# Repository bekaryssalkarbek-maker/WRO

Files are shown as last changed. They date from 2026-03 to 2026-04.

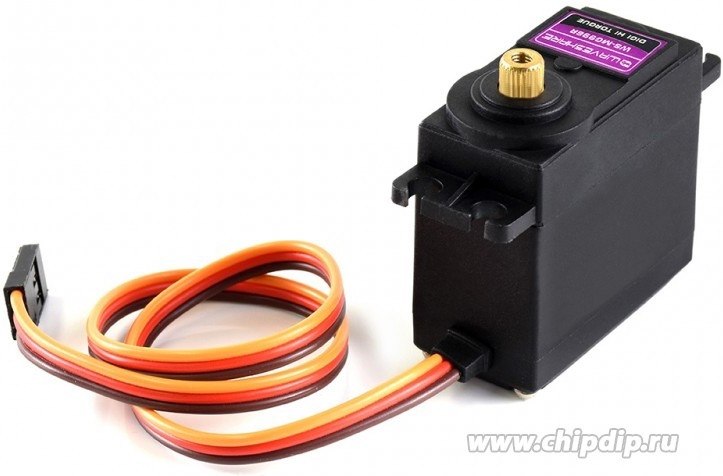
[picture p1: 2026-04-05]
Electronical components(photos)/mg996r v17.jpg

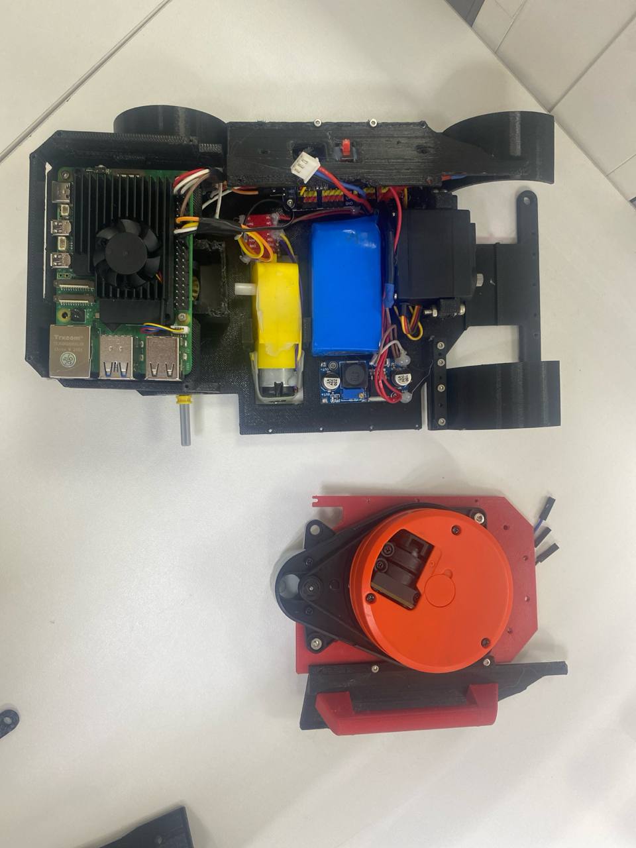
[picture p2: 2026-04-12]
Non-elecrtonical components(models)/building steps.jpg

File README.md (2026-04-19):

# 🚀 WRO 2025 Future Engineers – CyberBots
Welcome to the GitHub repository of Team CyberBots, participating in the World Robot Olympiad™ (WRO®) Future Engineers 2026 category. Our team designed and developed a compact autonomous vehicle inspired by real-world automotive engineering principles, with a design approach that visually reflects concepts similar to real vehicles and Mars rover-style exploration systems.

Our main objective was to build a robot that not only successfully completes the WRO challenge but also incorporates a realistic automotive-inspired design language. The external structure was intentionally designed to resemble a real vehicle in terms of proportions and layout, while maintaining full compliance with WRO constraints. Special attention was given to mechanical reliability, precise steering geometry, stable power architecture, sensor-based navigation, and modular electronic integration.

During development, each subsystem — including drivetrain, steering mechanism, perception system, onboard computing, and power distribution — was iteratively tested and optimized to achieve stable performance on the official 3 × 3 meter WRO competition field.

This repository documents our full engineering workflow, including system architecture, electrical schematics, component selection rationale, software logic structure, testing procedures, and validation results prepared for the WRO 2026 Future Engineers competition.

## 📚Table of Contents
## 📁 Project Structure

- 💾 Code
- 🔌 Electronical Components (CAD)
- 🔌 Electronical Components(photos)
- 📚 Engineer Journal
- ⚙  Non-Electronical Components
- 🔌 Schemes
- 👥 Team
- 🚗 Vehicle Photos
- 📁 SRC

## 📂Complete Documentation Structure
### Each folder contains comprehensive README documentation with specialized technical content
| 📁 Folder | 🎯 Technical Content | 
|---|---|
|  💾 Code | Software System |
|  | • Autonomous navigation algorithms |
| | • Camera color detection logic |
| | • LiDAR-based distance processing |
| | • Motor and steering control systems |
|  |
| 🔌 Electronical Components (CAD) | Electrical Design Models |
| | • CAD models of electronic layout |
| | • Component placement and integration |
| |  |
| 🔌 Electronical Components (Photos) | Electronics Implementation |
| | • Real photos of all electronic components |
| | • Individual component descriptions |
| | • Engineering problems and solutions |
| |  |
| 📚 Engineer Journal | Engineering Development Process |
| | • Design iterations and improvements |
| | • Problem solving and optimization |
| | • System-level engineering decisions |
| |  |
| ⚙ Non-Electronical Components | Mechanical Design |
| | • Full robot CAD model |
| | • Differential system design |
| | • Steering mechanism design |
| | • Chassis and structural architecture |
| | • 3D printing process and assembly stages |
| | • Design challenges and solutions |
| | • Individual CAD explanations for parts |
| |  |
| 🔌 Schemes | Electrical System Documentation |
| | • Electronics overview (photos + specs + quantity) |
| | • Full wiring schematic and system logic |
| | • Power distribution and current flow strategy |
| | • Assembly process of electrical system |
| | • Engineering problems and solutions |
| |  |
| 👥 Team | Team Information |
| | • Team members and roles |
| | • Coach/mentor information |
| | • Task distribution (mechanical, electronics, software, testing) |
| |  |
| 🚗 Vehicle Photos | Robot Documentation |
| | • CAD renders of robot |
| | • Real robot photos |
| | • Multi-angle system overview |
| |  |
| 📁 SRC | Testing & Resources |
| | • Autonomous navigation tests |
| | • Steering and drivetrain performance tests |
| | • Sensor calibration and validation |
| | • Competition condition testing |
| | • Debugging and additional resources |
| |  |

## 👥The Team
Team CyberBots includes passionate students working under the guidance of a coach. This is our first time competing in the WRO Future Engineers category (2026), where each member contributes unique skills to the project, including mechanical design, electronics, programming, and computer vision development.

Bekarys Shalkarbek
- Role: CAD modeling, electronics support, robot training and software development under coach supervision
- Background: 10th grade student, NIS FMN Astana
- Born: 2008, Kazakhstan
- Contact: bekaryssalkarbek@gmail.com

Anas Rustam
- Role: Engineering support, electronics integration, hardware development
- Background: School student
- Born: Kazakhstan

Coach:
Nursultan Bahit
- Role: Embedded Systems Engineer, CAD Designer, Robotics Engineer, Software & Backend Developer
- Background: Bachelor Degree, Cybersecurity, Astana IT University
- Born: 04.02.2007, Taraz, Kazakhstan
- Contact: nursultanbahit409@gmail.com

## 🎯Challenge Overview
### **Two distinct autonomous navigation challenges testing vehicle intelligence and precision**

</div>

### **🚀 Open Challenge**
<div align="center">

**Objective**: Complete three autonomous laps on dynamically configured tracks

| Aspect | Challenge | Our Solution |
|---|---|---|
| **Track Variability** | Random internal wall placements | Adaptive path planning algorithms |
| **Navigation** | Unknown track layouts each round | Robust wall-following with corner detection |
| **Performance** | Consistent lap times across variations | Optimized PID control and sensor fusion |
| **Precision** | Maintain course in narrow lanes | High-accuracy steering and speed control |

</div>

### **🚧 Obstacle Challenge**
<div align="center">

**Objective**: Navigate three laps with traffic sign compliance and precision parking

| Challenge Element | Requirement | Our Implementation |
|---|---|---|
| **Traffic Signs** | Red → Right bias<br>Green → Left bias | Real-time color detection with LAB colorspace |
| **Obstacle Avoidance** | Dynamic path adjustment | Smooth following at consistent distances |
| **Parking Maneuver** | Parallel parking after lap completion | Multi-stage parking with sensor validation |
| **Navigation** | Shortest path optimization | Efficient routing around obstacle combinations |
</div>

## 📊 **WRO 2025 Engineering Documentation Scoring (30 points total)**

| Scoring Area | Maximum Points | Our Documentation Coverage |
|---|---|---|
| **1. Mobility Management** | 4 points | Complete mechanical design, motor selection, steering system, assembly instructions |
| **2. Power & Sense Management** | 4 points | Power systems, sensor integration, wiring diagrams, component specifications |
| **3. Obstacle Management** | 4 points | Navigation algorithms, parking strategies, source code with detailed comments |
| **4. Pictures – Team and Vehicle** | 4 points | Multi-angle vehicle photos, team photos, component labeling |
| **5. Performance Videos** | 4 points | Complete challenge demonstrations with commentary and analysis |
| **6. GitHub Utilization** | 4 points | Version control, structured documentation, regular commits |
| **7. Engineering Factor** | 4 points | Custom design and manufacturing throughout the vehicle |
| **8. Overall Judge Impression** | 2 points | Clear communication enabling easy replication |
| **Total Documentation Score** | **30 points** | **(≈25% of total competition score)** |
</div>

## 🤖Our Robot
### **Vehicle Photos**
The following folder contain the final assembled robot from different perspectives. They demonstrate the chassis structure, steering mechanism, drivetrain layout, bumper design, LED headlights, and placement of key electronic components such as the Raspberry Pi and LiDAR sensor.

### **Photos**
#### **Front photo**
**Focus:** Lidar, Camera, Stearing system, LED headlights
- Lidar: Xiaomi Lidar Sensor (Used for distance measurement and obstacle detection to support accurate navigation and safe robot movement during competition runs.)
- Camera: USB 8MP 4K 60fps Camera(Used for color detection and environment recognition to support navigation decisions during robot movement, while distance measurement is handled by the LiDAR sensor.)
- Stearing system: Mechanism responsible for controlling the direction of the robot’s front wheels, enabling precise turning and stable navigation during movement.
- LED headlights: Used primarily for aesthetic purposes, improving the robot’s visual appearance without affecting its functional performance during operation

Front photo

#### Core Processing Architecture
- Primary Computing Unit:Raspberry Pi 5 (1GB) single-board computer with Quad-core 2.4 GHz Cortex-A76 CPU, VideoCore VII GPU, Wi-Fi 802.11ac, Bluetooth 5.0, and 40-pin GPIO interface. Responsible for vision processing, LiDAR data handling, navigation logic, and overall system coordination.
- PWM Control Expansion:PCA9685 16-Channel PWM Driver (I2C) with 12-bit resolution (4096 steps) and adjustable PWM frequency (24–1526 Hz), used for stable actuator signal generation and precise control of steering systems.
- Distributed Control Strategy:Separation between high-level navigation processing on Raspberry Pi 5 and low-level motor actuation through DRV8833 dual H-bridge motor driver ensures reliable real-time control performance.

#### Perception System
- Front Visual Navigation:USB 8MP Camera with IMX415 sensor supporting 4K resolution and wide-angle field of view, used for track detection, color recognition, and environmental interpretation.
- Environmental Mapping:RPLIDAR 360° laser scanner with approximately 10–12 meters measurement range, enabling obstacle detection and spatial awareness during autonomous navigation.
- Sensor Fusion Logic:Combined processing of camera-based visual perception and LiDAR distance measurements improves navigation reliability under varying competition conditions.

#### Propulsion and Control
- Drive System:TT DC Gear Motor (3–6 V, gear ratio 1:48) with 130–290 RPM no-load speed and 160–240 mA no-load current provides stable drivetrain motion.
- Steering Mechanism:MG996R V17 Digital Servo Motor with metal gears, operating voltage 4.8–7.2 V, speed 0.17 s/60°, and approximately 180° rotation range enables precise steering control.
- Motor Control Interface:DRV8833 Dual H-Bridge Motor Driver supporting 2.7–10.8 V operating voltage and up to 1.5 A per channel output current with PWM speed control capability.
- Power Management Architecture:Custom 2S LiPo Battery (7.4 V, 3000 mAh) combined with HW-411 LM2596 DC-DC Buck Converter (input 4–40 V, output 1.25–35 V adjustable, up to 3 A) ensures stable voltage regulation across all subsystems.
- Electrical Safety Control:SS12D10 SPDT Slide Switch (90°) used as the primary system power isolation switch for safe startup and shutdown operations.

### Potential Future Improvements (Overall Vehicle)

- Improve vehicle speed by integrating a more powerful drivetrain motor with higher torque and better acceleration characteristics while maintaining the current robot dimensions. This upgrade will increase responsiveness and allow faster navigation on the competition track.
- Enhance drivetrain efficiency by optimizing gear ratio selection and reducing mechanical friction within the transmission system. These improvements will support smoother motion and more stable high-speed performance.
- Further improve power distribution stability to support higher peak acceleration without voltage drops by refining voltage regulation stages and optimizing current flow between computing, sensing, and actuation subsystems.

## 🔧 Electronic Systems
| Components | Image  | Description | Quantity | 
|---|---|---|---|
| Battery 7.4V |  Battary 7 4 v | Lithium polymer battery pack / custom 2S LiPo battery – 7.4V, 3000mAh, Charge 0.5C, Discharge 1C, Size 13×42.5×98 mm, Weight ~108 g. | 1  | 
| yellow toymotor dims |  yellow_toymotor_dims |Yellow DC 3V–6V Gear Motor TT for Intelligent Car / Robot Wheels – Voltage 3–6V, No-load current 160–240 mA, No-load speed 130–290 rpm, Gear ratio 1:48, Single axis. |  1  | 
| mg996r v17 | mg996r v17 | MG996R V17 Servo Motor – High torque, Digital, Rotation ~180°, Operating voltage 4.8–7.2 V, Speed 0.17 s/60° (6 V), Metal gears, Standard size. | 1 | 
| HW-411 | HW-411 | HW‑411 DC‑DC Buck Converter Module – Adjustable step‑down voltage regulator (LM2596S), Input 4–40 V, Output 1.25–35 V (adjustable), Max current ≈3 A, High efficiency (~92%), Overheat and short‑circuit protectio | 2 | 
| USB 8MP 4K 60fps Camera | Cam V2 1 v1 | USB 8MP 4K 60fps Camera with IMX415 Sensor and Microphone, Day & Night Wide-Angle Surveillance HD CCTV System |  1  | 
| DRV8833 | DRV8833  | DRV8833 Dual DC Motor Driver Module – Dual H-bridge motor driver, operating voltage 2.7–10.8 V, controls 2 DC motors, output current 1.5 A per channel, supports PWM control, built-in protection circuits. |  1  | 
| PCA9685 v18 | PCA9685 v18  | PCA9685 16-Channel PWM Servo Driver Module (I2C) – Controls up to 16 servos, 12-bit PWM resolution (4096 steps), communication via I2C (SDA/SCL), logic voltage 3.3 V / 5 V compatible, adjustable PWM frequency ≈24–1526 Hz, supports chaining up to 62 modules. |  1 | 
| RASPBERRY_PI5_1 | RASPBERRY_PI5_1  | Raspberry Pi 5 (1GB) – Quad-core 2.4 GHz Cortex-A76 CPU, 1 GB LPDDR4X RAM, VideoCore VII GPU, Wi-Fi (802.11ac) + Bluetooth 5.0, Gigabit Ethernet, 2× USB 3.0 + 2× USB 2.0, dual 4K HDMI output, PCIe 2.0, 40-pin GPIO, power 5 V / 5 A via USB-C. |  1  |
| RPLIDAR | RPLIDAR  | Xiaomi LiDAR Sensor (e.g., TOF / 360°)* – Long‑range distance measurement up to ~10–12 m, 360° scanning, high‑precision time‑of‑flight (ToF) / laser ranging, fast sampling, low‑power, interface UART / I2C / SPI (зависит от модели), used for SLAM and robot navigation. |  1  | 
| SS12D10_90_Degree | SS12D10_90_Degree | SS12D10 90° Slide Switch (DIP) – SPDT slide switch, 90° actuation, DIP package, rated current ≈0.3–1 A, voltage ≈12–24 V DC, used for power/control switching in circuits. | 1  | 

**Component Sourcing Rules:** Direct product links and pricing information are intentionally not included to ensure long-term accessibility and avoid outdated references. All listed components can be easily found online using their names and images, while their authenticity can be confirmed through the datasheets provided in this repository.

### **⚡️Complete Wiring System**
#### **Wiring Schematic & Physical Implementation**
#### **1**
full scheme

#### **2**




1) Complete hand-drawn and digitally traced wiring schematic showing full electrical connections
2) Physical implementation demonstrating socket-based construction of the schematic

## Power Management Innovation

During system integration, we identified the necessity of implementing a stable and efficient power distribution architecture capable of supporting both high-current drivetrain components and sensitive computing modules operating simultaneously.

Our robot uses a 7.4V (2S) LiPo battery as the primary energy source. To ensure reliable voltage regulation for onboard electronics, we implemented a dedicated power management structure based on the HW-411 (LM2596) DC-DC buck converter module, providing stable regulated voltage for critical subsystems including the Raspberry Pi 5, sensors, and control electronics.

To improve operational safety and prevent unintended battery discharge during inactive states, an SS12D10 SPDT slide switch was integrated as the primary hardware-level power isolation mechanism controlling system startup and shutdown.

Additionally, we applied a separated power distribution strategy between computational modules and actuator subsystems. This approach reduces electrical noise from motors, prevents voltage drops during peak load conditions, and improves overall stability of perception and navigation performance during autonomous operation.

This structured power architecture significantly increases electrical reliability, protects sensitive components, and ensures consistent system behavior under dynamic competition conditions.

### Engineering Solution:

- **Structural Layout Optimization:** Internal components reorganized using electronics-first placement to avoid interference and improve weight distribution.

- **Mechanical Strength vs Weight Optimization:** Gyroid infill selected after testing multiple patterns to achieve best balance of strength and low weight.

- **Sensor Integration Stability:** Dedicated mounts and cable routing implemented for stable LiDAR and camera operation without mechanical interference.

### Modular Manufacturing Strategy Advantages
Our robot architecture was intentionally designed to support iterative development and serviceability during competition preparation:

- Rapid mechanical adjustments without external fabrication delays
- Independent subsystem upgrades without full system redesign
- Fast component replacement during testing and competition
- Continuous weight distribution optimization
- Improved robustness through direct assembly verification
  
This strategy ensured that the robot remained adaptable throughout the engineering cycle while maintaining competition reliability.

## Development Convenience Features
Implementation of accessible Raspberry Pi port openings significantly improved development workflow, enabling fast code uploading, debugging, and continuous testing without disassembling the robot.

Back photo
Right side photo

## ⚙Mechanical Systems
Our mechanical design philosophy centers on achieving maximum capability within minimal dimensions through innovative engineering and precision manufacturing.

### Core Mechanical Specifications
- **Overall Dimensions:** 69mm (L) × 53mm (W) × 57mm (H)
- **Total Mass:** Approximately 130 grams
- **Structural Material:** 3D-printed ABS for optimal strength-to-weight ratio
- **Drive Configuration:** Rear-wheel drive with custom differential
- **Steering System:** True Ackermann geometry with precision linkage

General photo
CAD general photo

## Manufacturing File Repository

| Component  | Quantity | Description | CAD Photo Preview |
|---|---|---|---|
| **Main Chassis** | 1 | Primary structure with integrated mounting system | Снимок экрана 2026-04-19 041640  |
| **LEGO 4-Gear Differential**  | 1 |A LEGO differential is a drivetrain component that distributes torque between the left and right wheels, allowing them to rotate at different speeds during turns for smooth and stable cornering. |  |
| **Bumper** | 1 |  A front bumper is a structural protective component mounted on the front of the robot, designed to absorb minor impacts and protect internal systems while maintaining clearance for the steering mechanism, and it also serves as a mounting point for LED headlights | Снимок экрана 2026-04-16 015010 |
| **Back right wheel fender** |  1 |  Protective wheel panel providing structural protection and body support. | Снимок экрана 2026-04-16 142714  |
| **Back left wheel fender** | 1 | Protective wheel panel providing structural protection and body support. | Снимок экрана 2026-04-16 142714 |
| **Front left wheel fender** | 1 | Protective wheel panel providing structural protection and necessary clearance for steering rotation. | Снимок экрана 2026-04-16 142253 | 
| **Front right wheel fender** | 1 | Protective wheel panel providing structural protection and necessary clearance for steering rotation. | Снимок экрана 2026-04-16 142253  | 
| **Disk for wheel** | 4 | Custom wheel disk ensuring reliable connection between the wheel and drivetrain. | Снимок экрана 2026-04-16 120709  |
| **Servo Gear** | 1 |  Transmission gear transferring rotation from the servo motor to the steering mechanism. | Снимок экрана 2026-04-16 113454  | 
| **Left holder** | 1 | Structural holder designed to simplify safe robot handling and transportation. | Снимок экрана 2026-04-16 143249 |
| **Right holder** | 1 | Structural holder designed to simplify safe robot handling and transportation. | Снимок экрана 2026-04-16 143249  | 
| **Lidar holder** | 1 | Mount designed for stable LiDAR sensor installation. | Снимок экрана 2026-04-16 140928 | 
| **Lower left body panel** | 1 | Body panel used to reinforce chassis structure. |  Снимок экрана 2026-04-16 140342 | 
| **Lower right body panel** |  1 | Body panel used to reinforce chassis structure. | Снимок экрана 2026-04-16 145644  | 
| **Upper right body panel** |  1 | Body panel used to protect internal robot components. | Снимок экрана 2026-04-16 135838 |  
| **Upper left body panel** |  1 | Body panel used to protect internal robot components. | Снимок экрана 2026-04-16 140112  |  
| **Motor holder** |  1 | Mount designed for secure drivetrain motor fixation. | Снимок экрана 2026-04-16 113226 | 
| **Raspberry upper holder** |  1 | Mount used to secure the Raspberry Pi board. |  Снимок экрана 2026-04-16 140928 | 
| **Raspberry lower holder** |  1 |  Mount used to secure the Raspberry Pi board. | Снимок экрана 2026-04-16 113956 |
| **Swich 2 Axis** |  1 | Mount designed for installation of the 2-axis control switch. | Снимок экрана 2026-04-16 141304 | 
| **Wheel 45 degree Rotator** |  1 | Steering mechanism component enabling wheel rotation up to 45°. |  Снимок экрана 2026-04-16 120034 |  
| **180 degree gea** |  1 | Gear used for rotation of front wheels within the steering mechanism. | Снимок экрана 2026-04-16 113746 |
| **Wheel holder left** | 1 | Mount designed to secure the wheel and maintain correct alignment. | Снимок экрана 2026-04-16 135411 | 
| **Lego wheels** | 4 |  Standard LEGO wheel used for robot movement, providing traction, stability, and reliable motion on the competition field. | Снимок экрана 2026-04-16 165149 |  

### Building
Performance Engineering Analysis

### Assembly Sequence:
#### **Phase 1: Base Structure & Foundation Assembly**

- **Bottom Layer Construction:** The assembly process began with the bottom structural layer, forming the main chassis “floor” as the primary load-bearing foundation for all components
 
- **Electronics Mounting:** Installation of the Raspberry Pi and supporting electronic components directly onto the base layer for compact and stable integration

- **Wiring & Connectivity Setup:** Organization and connection of all power and control wiring to ensure clean routing and accessibility

- **Motor Installation:** Integration of the Yellow DC TT Gear Motor (3V–6V, 130–290 rpm, 1:48 gear ratio) as the main drivetrain motor, mounted securely onto the base structure

- **Power System Integration:** Placement of the battery in an optimized position to maintain stable weight distribution and balance

- **Initial Mechanical Alignment:** Early verification of structural alignment to ensure correct positioning of drivetrain components before upper assembly

#### **Phase 2: Upper Structure & Mechanical Systems**

- **Chassis Completion:** Installation of upper structural elements to protect internal systems while maintaining modular accessibility

- **Steering System Integration:** Assembly of the front steering mechanism, including rotator system, with adjustments to avoid spatial conflicts with the bumper

- **Wheel & Differential Installation:** Final integration of wheels and LEGO differential system, ensuring smooth torque transfer and correct alignment with the drivetrain

#### **Phase 3: Final System Assembly & Validation**

- **Full System Integration:** Connection of mechanical, electrical, and control systems into a unified working robot

- **Structural Verification:** Final checks of mechanical stability, component fitment, and assembly integrity

- **Functional Testing:** Validation of drivetrain efficiency, steering response, and overall robot movement performance

Building

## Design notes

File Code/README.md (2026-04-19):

# Code Documentation
This folder contains Python programs developed for Team CyberBots’s WRO 2026 Future Engineers project, specifically designed to implement the robot’s autonomous navigation system, vision processing algorithms, and movement control logic.

## 🤖Autonomous Navigation Software Architecture(Open Challenge)

The CyberBots robot uses a vision-based autonomous navigation system implemented in Python using the OpenCV library and executed on a Raspberry Pi 5 computing platform. The algorithm enables real-time environment perception and adaptive steering control without external infrastructure.

The navigation logic is based on continuous camera frame analysis divided into three independent Regions of Interest (ROI):

left region (left boundary detection)
right region (right boundary detection)
center region (forward obstacle detection)

Each region is processed separately using grayscale thresholding to estimate the presence of walls or free space relative to the robot’s position inside the track.

To improve stability and reduce noise influence from camera input, an exponential smoothing filter is applied to the detected wall signals:

This filtering method prevents sudden steering oscillations and ensures smoother trajectory correction during motion.

Steering control is implemented using proportional error-based correction between left and right boundary detection signals. The difference between detected wall intensities determines the steering angle adjustment applied to the servo motor:

This allows continuous real-time trajectory alignment while maintaining forward motion stability.

Additionally, adaptive brightness compensation is implemented inside the forward detection region. When high illumination conditions are detected, the obstacle detection sensitivity is automatically adjusted to maintain reliable perception accuracy under varying lighting conditions during competition runs.

When the algorithm detects sufficient open space in front of the robot, a controlled turning procedure is activated. During this maneuver, the robot monitors frame-to-frame grayscale changes to determine when environmental motion stabilizes. This visual stabilization logic prevents premature steering reset and ensures accurate completion of the turning sequence.

The integration of region-based perception, signal smoothing, proportional steering correction, and adaptive brightness handling results in a reliable and computationally efficient autonomous navigation system optimized for the WRO Future Engineers competition environment.

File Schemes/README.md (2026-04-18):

# **Schemes Documentation**
The following schematic presents the electrical connection layout of the robot, showing how the Raspberry Pi, LiDAR sensor, camera, steering servo, drivetrain motor, and power system are integrated. This diagram helps visualize signal routing, power distribution, and overall system interaction for reliable robot performance.

## **🎯Electrical Design Goal**
The purpose of this schematic is to clearly illustrate the electrical connections between the main components of the robot, including the Raspberry Pi, LiDAR sensor, camera, steering servo, drivetrain motor, and power system, ensuring correct integration, troubleshooting support, and reliable system operation.

## **📋Complete Bill of Materials(Electronical)/BOM**
| Components | Image  | Description | Quantity | 
|---|---|---|---|
| Battery 7.4V |  Battary 7 4 v | Lithium polymer battery pack / custom 2S LiPo battery – 7.4V, 3000mAh, Charge 0.5C, Discharge 1C, Size 13×42.5×98 mm, Weight ~108 g. | 1  | 
| yellow toymotor dims |  yellow_toymotor_dims |Yellow DC 3V–6V Gear Motor TT for Intelligent Car / Robot Wheels – Voltage 3–6V, No-load current 160–240 mA, No-load speed 130–290 rpm, Gear ratio 1:48, Single axis. |  1  | 
| mg996r v17 | mg996r v17 | MG996R V17 Servo Motor – High torque, Digital, Rotation ~180°, Operating voltage 4.8–7.2 V, Speed 0.17 s/60° (6 V), Metal gears, Standard size. | 1 | 
| HW-411 | HW-411 | HW‑411 DC‑DC Buck Converter Module – Adjustable step‑down voltage regulator (LM2596S), Input 4–40 V, Output 1.25–35 V (adjustable), Max current ≈3 A, High efficiency (~92%), Overheat and short‑circuit protectio | 2 | 
| USB 8MP 4K 60fps Camera | Cam V2 1 v1 | USB 8MP 4K 60fps Camera with IMX415 Sensor and Microphone, Day & Night Wide-Angle Surveillance HD CCTV System |  1  | 
| DRV8833 | DRV8833  | DRV8833 Dual DC Motor Driver Module – Dual H-bridge motor driver, operating voltage 2.7–10.8 V, controls 2 DC motors, output current 1.5 A per channel, supports PWM control, built-in protection circuits. |  1  | 
| PCA9685 v18 | PCA9685 v18  | PCA9685 16-Channel PWM Servo Driver Module (I2C) – Controls up to 16 servos, 12-bit PWM resolution (4096 steps), communication via I2C (SDA/SCL), logic voltage 3.3 V / 5 V compatible, adjustable PWM frequency ≈24–1526 Hz, supports chaining up to 62 modules. |  1 | 
| RASPBERRY_PI5_1 | RASPBERRY_PI5_1  | Raspberry Pi 5 (1GB) – Quad-core 2.4 GHz Cortex-A76 CPU, 1 GB LPDDR4X RAM, VideoCore VII GPU, Wi-Fi (802.11ac) + Bluetooth 5.0, Gigabit Ethernet, 2× USB 3.0 + 2× USB 2.0, dual 4K HDMI output, PCIe 2.0, 40-pin GPIO, power 5 V / 5 A via USB-C. |  1  |
| RPLIDAR | RPLIDAR  | Xiaomi LiDAR Sensor (e.g., TOF / 360°)* – Long‑range distance measurement up to ~10–12 m, 360° scanning, high‑precision time‑of‑flight (ToF) / laser ranging, fast sampling, low‑power, interface UART / I2C / SPI (зависит от модели), used for SLAM and robot navigation. |  1  | 
| SS12D10_90_Degree | SS12D10_90_Degree | SS12D10 90° Slide Switch (DIP) – SPDT slide switch, 90° actuation, DIP package, rated current ≈0.3–1 A, voltage ≈12–24 V DC, used for power/control switching in circuits. | 1  | 

**Component Sourcing Rules:** Direct product links and pricing information are intentionally not included to ensure long-term accessibility and avoid outdated references. All listed components can be easily found online using their names and images, while their authenticity can be confirmed through the datasheets provided in this repository.

## **⚡️Complete Wiring System**
### **Wiring Schematic & Physical Implementation**
### **1**
full scheme

### **2**




1) Complete hand-drawn and digitally traced wiring schematic showing full electrical connections
2) Physical implementation demonstrating socket-based construction of the schematic

### **Engineering Documentation Excellence**

- **Professional Schematic:** All electrical connections between the Raspberry Pi, LiDAR sensor, camera, steering servo, drivetrain motor, and power system are clearly documented for accurate system integration

- **Modular Architecture:** Key electronic components are mounted using dedicated holders and accessible ports to simplify maintenance, testing, and component replacement

- **Cable Management:** Organized wiring layout ensures stable power delivery, reduces cable stress, and improves overall system reliability during robot operation

## **⚡Power Management System**
| Line | Source | Consumers | Voltage | Avg Current | Peak Current |
|---|---|---|---|---|---|
| A (Logic) | DC-DC Converter #1 | Raspberry Pi 4 | 5V | 0.6–1.2A | up to 2A |
| A (Logic) | DC-DC Converter #1 | RPLIDAR | 5V | 0.5–1A | ~1A |
| A (Logic) | DC-DC Converter #1 | PCA9685 (logic) | 3.3–5V | ~20mA | ~20mA |
| B (Servo) | DC-DC Converter #2 | MG996R (1 servo) | 5–6V | 0.1–0.5A | up to 2.5A |
| C (Motors) | Battery 7.4V Li-Po | DRV8833 + DC motors | 7.4V | 1–2A | 4–6A |
| Common Bus | Battery | Shared system ground (GND) | 0V | — | — |

**Power Management Innovation**

During system integration, we identified the necessity of implementing a stable and efficient power distribution architecture capable of supporting both high-current drivetrain components and sensitive computing modules operating simultaneously.

Our robot uses a 7.4V (2S) LiPo battery as the primary energy source. To ensure reliable voltage regulation for onboard electronics, we implemented a dedicated power management structure based on the HW-411 (LM2596) DC-DC buck converter module, providing stable regulated voltage for critical subsystems including the Raspberry Pi 5, sensors, and control electronics.

Additionally, we applied a separated power distribution strategy between computational modules and actuator subsystems. This approach reduces electrical noise from motors, prevents voltage drops during peak load conditions, and improves overall stability of perception and navigation performance during autonomous operation.

## **🎯Strategic Engineering Choice Analysis:**
### Strategic Manufacturing Approach Analysis

Our robot was developed using a hybrid in-house manufacturing strategy that prioritizes rapid iteration, modularity, reliability, and competition readiness. Instead of relying on fully outsourced fabrication, we implemented a flexible engineering workflow allowing continuous improvement throughout testing cycles.

Building

| Aspect | Fully Outsourced Fabrication | Hybrid In-House Manufacturing (Our Approach) | Engineering Rationale |
|---|---|---|---|
| Development Speed | Long fabrication turnaround | Immediate mechanical adjustments | Enables fast iteration during testing |
| Cost Efficiency | High per revision cost | Low-cost prototyping workflow | Sustainable for student engineering projects |
| Structural Adaptability | Fixed geometry after production | Adjustable structural configuration | Supports rapid competition-driven redesign |
| Integration Flexibility | Difficult subsystem replacement | Modular subsystem architecture | Allows efficient upgrades and tuning |
| Reliability Control | Dependent on external manufacturing | Fully controlled internal assembly | Ensures predictable system behavior |
| Engineering Understanding | Limited exposure to fabrication details | Full system-level ownership | Strengthens applied robotics engineering skills |

---

### Modular Manufacturing Strategy Advantages

Our robot architecture was intentionally designed to support iterative development and serviceability during competition preparation:

- Rapid mechanical adjustments without external fabrication delays
- Independent subsystem upgrades without full system redesign
- Fast component replacement during testing and competition
- Continuous weight distribution optimization
- Improved robustness through direct assembly verification

This strategy ensured that the robot remained adaptable throughout the engineering cycle while maintaining competition reliability.

---

### Integrated Mechanical–Electrical Production Strategy

The robot structure combines mechanical accessibility with electrical reliability through a modular subsystem layout.

| Design Feature | Implementation Benefit |
|---|---|
| Modular chassis structure | Enables quick geometry optimization |
| Socket-based electronics mounting | Supports fast diagnostics and replacement |
| Segmented power distribution architecture | Improves electrical stability under load |
| Adjustable sensor mounting interfaces | Allows rapid calibration refinement |
| Accessible drivetrain assembly | Simplifies tuning and maintenance |

---

### **Competition-Oriented Engineering Goal**

Our manufacturing workflow follows a competition-focused engineering methodology:

- prioritize reliability over complexity
- design for maintainability during live testing
- ensure subsystem independence
- enable fast iteration between test sessions
- maintain full control over system architecture

This approach allowed us to continuously refine both mechanical and electrical subsystems while preserving stability and repeatability across testing runs.

## 🛠 Engineering Challenges & Solutions

### Structural Layout Optimization

During development, one of the main challenges was organizing the internal structure of the robot while maintaining compact dimensions and stable weight distribution. Since the electronics were mounted directly on the base layer, careful placement was required to avoid interference between components and ensure reliable operation.

Root Cause Analysis:
- Limited chassis space with multiple electronic modules installed on the base platform  
- Risk of steering mechanism interference with the front bumper  
- Need for stable placement of Raspberry Pi, LiDAR sensor, and battery for balanced weight distribution  
- Requirement to maintain accessibility to Raspberry Pi ports for configuration and testing  

Engineering Solution:
- Electronics-first architecture implemented by mounting Raspberry Pi and core modules on the base layer before drivetrain installation  
- Steering geometry adjusted to maintain safe rotation clearance near the front bumper  
- Battery placement optimized to improve center-of-mass stability  
- External access to Raspberry Pi ports preserved for easier setup and debugging  

---

### Mechanical Strength vs Weight Optimization

Another engineering challenge involved selecting the optimal internal structure for 3D-printed components to achieve sufficient strength without increasing robot weight.

Root Cause Analysis:
- Need to reduce overall robot mass for improved movement efficiency  
- Requirement to maintain durability of load-bearing printed components  
- Multiple infill pattern options available (gyroid, honeycomb, linear, cubic) with different performance characteristics  

Engineering Solution:
- Comparative evaluation of several infill structures performed during prototyping  
- Gyroid infill selected due to its balanced strength-to-weight characteristics  
- Printing parameters optimized to ensure reliable structural performance during competition runs  

---

### Sensor Integration Stability

Integration of LiDAR and camera systems required careful positioning to ensure reliable environmental perception without mechanical obstruction.

Root Cause Analysis:
- LiDAR required stable mounting for accurate distance measurement  
- Camera required clear forward orientation for color detection  
- Risk of wiring interference with moving steering components  

Engineering Solution:
- Dedicated LiDAR holder designed for stable sensor positioning  
- Camera placement optimized for reliable color detection during navigation  
- Organized cable routing implemented to prevent interference with steering movement

## **📚References of components**
| Component | Files | Key Specifications | Qty |
|---|---|---|-----|
| Yellow TT Gear Motor | [Yellow DC 3V–6V Gear Motor TT_specification.pdf](https://github.com/user-attachments/files/26836848/Yellow.DC.3V.6V.Gear.Motor.TT_specification.pdf) | DC 3V–6V gear motor, no-load current 160–240 mA, speed 130–290 rpm, gear ratio 1:48 | 1 |
| MG996R V17 Servo |  [MG996R_specification.pdf](https://github.com/user-attachments/files/26836880/MG996R_specification.pdf) | High torque digital servo, 4.8–7.2V, speed 0.17 s/60° (6V), metal gears, ~180° rotation | 1 |
| HW-411 Buck Converter | [HW‑411 DC‑DC Buck Converter Module_specification.pdf](https://github.com/user-attachments/files/26836905/HW.411.DC.DC.Buck.Converter.Module_specification.pdf) | LM2596-based step-down converter, input 4–40V, output 1.25–35V, up to ~3A, high efficiency (~92%) | 2 |
| USB 8MP 4K Camera | [USB 8MP 4K 60fps Camera.specification.pdf](https://github.com/user-attachments/files/26837379/USB.8MP.4K.60fps.Camera.specification.pdf)| IMX415 sensor, 8MP resolution, 4K support, wide-angle USB camera module | 1 |
| DRV8833 Motor Driver | [DRV8833_specification.pdf](https://github.com/user-attachments/files/26837410/DRV8833_specification.pdf) | Dual H-bridge driver, 2.7–10.8V, up to 1.5A per channel, PWM control, built-in protection | 1 |
| PCA9685 Servo Driver | [MG996R_specification.pdf](https://github.com/user-attachments/files/26837420/MG996R_specification.pdf) | 16-channel PWM driver, 12-bit resolution, I2C interface, 3.3V/5V compatible, 24–1526 Hz frequency | 1 |
| Raspberry Pi 5 (1GB) | [MG996R_specification.pdf](https://github.com/user-attachments/files/26837428/MG996R_specification.pdf) | Quad-core 2.4 GHz Cortex-A76, 1GB RAM, dual 4K HDMI, Wi-Fi, Bluetooth, USB 3.0, GPIO 40-pin | 1 |
| RPLIDAR |  | 360° laser scanning LiDAR, up to ~10–12 m range, used for SLAM and navigation | 1 |
| SS12D10 Slide Switch | [SS12D10_90_Degree_specification.pdf](https://github.com/user-attachments/files/26837433/SS12D10_90_Degree_specification.pdf) | SPDT slide switch, 90° actuation, ~12–24V DC rated, used for power control | 1 |

## **✅Engineering Validation**

This comprehensive electrical documentation provides full transparency into our robot’s system architecture, component selection, and integration methodology. Each component was carefully chosen and tested to ensure reliable interaction between control, sensing, and actuation systems.

The overall electrical design has been optimized for stability, maintainability, and consistent performance under WRO Future Engineers competition conditions.

- System Integration: Connection of all mechanical, electrical, and control systems into a unified architecture
- Final Validation: Structural verification, alignment checks, and full drivetrain and steering performance testing

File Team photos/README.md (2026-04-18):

# Team Photos
This folder contains official and informal photos of Team CyberBots, showcasing our team collaboration, development process, and engineering progress during the WRO Future Engineers 2026 project.
## Member List

Bekarys Shalkarbek
- Role: CAD modeling, electronics support, robot training and software development under coach supervision
- Background: 10th grade student, NIS FMN Astana
- Born: 2008, Kazakhstan
- Contact: bekaryssalkarbek@gmail.com
я

Anas Rustam
- Role: Engineering support, electronics integration, hardware development
- Background: School student
- Born: Kazakhstan
напарник

Coach:
Nursultan Bahit
- Role: Embedded Systems Engineer, CAD Designer, Robotics Engineer, Software & Backend Developer
- Background: Bachelor Degree, Cybersecurity, Astana IT University
- Born: 04.02.2007, Taraz, Kazakhstan
- Contact: nursultanbahit409@gmail.com
тренер

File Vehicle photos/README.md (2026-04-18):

# **Vehicle Photos**
The following folder contain the final assembled robot from different perspectives. They demonstrate the chassis structure, steering mechanism, drivetrain layout, bumper design, LED headlights, and placement of key electronic components such as the Raspberry Pi and LiDAR sensor.

## **Photos**
### **Front photo**
**Focus:** Lidar, Camera, Stearing system, LED headlights
- Lidar: Xiaomi Lidar Sensor (Used for distance measurement and obstacle detection to support accurate navigation and safe robot movement during competition runs.)
- Camera: USB 8MP 4K 60fps Camera(Used for color detection and environment recognition to support navigation decisions during robot movement, while distance measurement is handled by the LiDAR sensor.)
- Stearing system: Mechanism responsible for controlling the direction of the robot’s front wheels, enabling precise turning and stable navigation during movement.
- LED headlights: Used primarily for aesthetic purposes, improving the robot’s visual appearance without affecting its functional performance during operation

Front photo

### **Back photo**
**Focus:** Lidar, Raspberry Pi, differential system, wires
 - Raspberry Pi: Raspberry Pi5 ports for external connections and system access
 - Lidar: Xiaomi Lidar Sensor (Used for distance measurement and obstacle detection to support accurate navigation and safe robot movement during competition runs.)
 - Differential system: 4-gear differential system ensuring smooth torque distribution between wheels
 - Wires: Organized wiring for stable power delivery and signal transmission between components
   
Back photo 

### **Left/Right side photo**
**Focus:** Lidar, button, switch, Raspberry Pi ports
 - Lidar: Xiaomi Lidar Sensor (Used for distance measurement and obstacle detection to support accurate navigation and safe robot movement during competition runs.)
 - Button and switch for turning the robot on and off and controlling power flow to the system
 - Raspberry Pi: Raspberry Pi5 ports for connecting peripherals such as keyboard, mouse, and display
 
Left side photo
Right side photo

### **Botton photo**

**Focus:** 4-gear differential, steering system, motor holder, LEGO wheels

4-Gear Differential: LEGO 4-gear differential system used to distribute torque efficiently between the drive wheels, improving traction and enabling smoother turning during autonomous movement 
Steering System: Front steering mechanism based on a servo-controlled linkage structure, providing precise wheel angle control for accurate navigation on the WRO field 
Motor Holder: Custom motor mounting structure designed to securely fix the drivetrain motor to the chassis while maintaining alignment with the transmission system 
LEGO Wheels (4 units): Four LEGO wheels integrated into the drivetrain and steering system to ensure stable movement, reliable traction, and consistent performance during competition runs 

Botton photo

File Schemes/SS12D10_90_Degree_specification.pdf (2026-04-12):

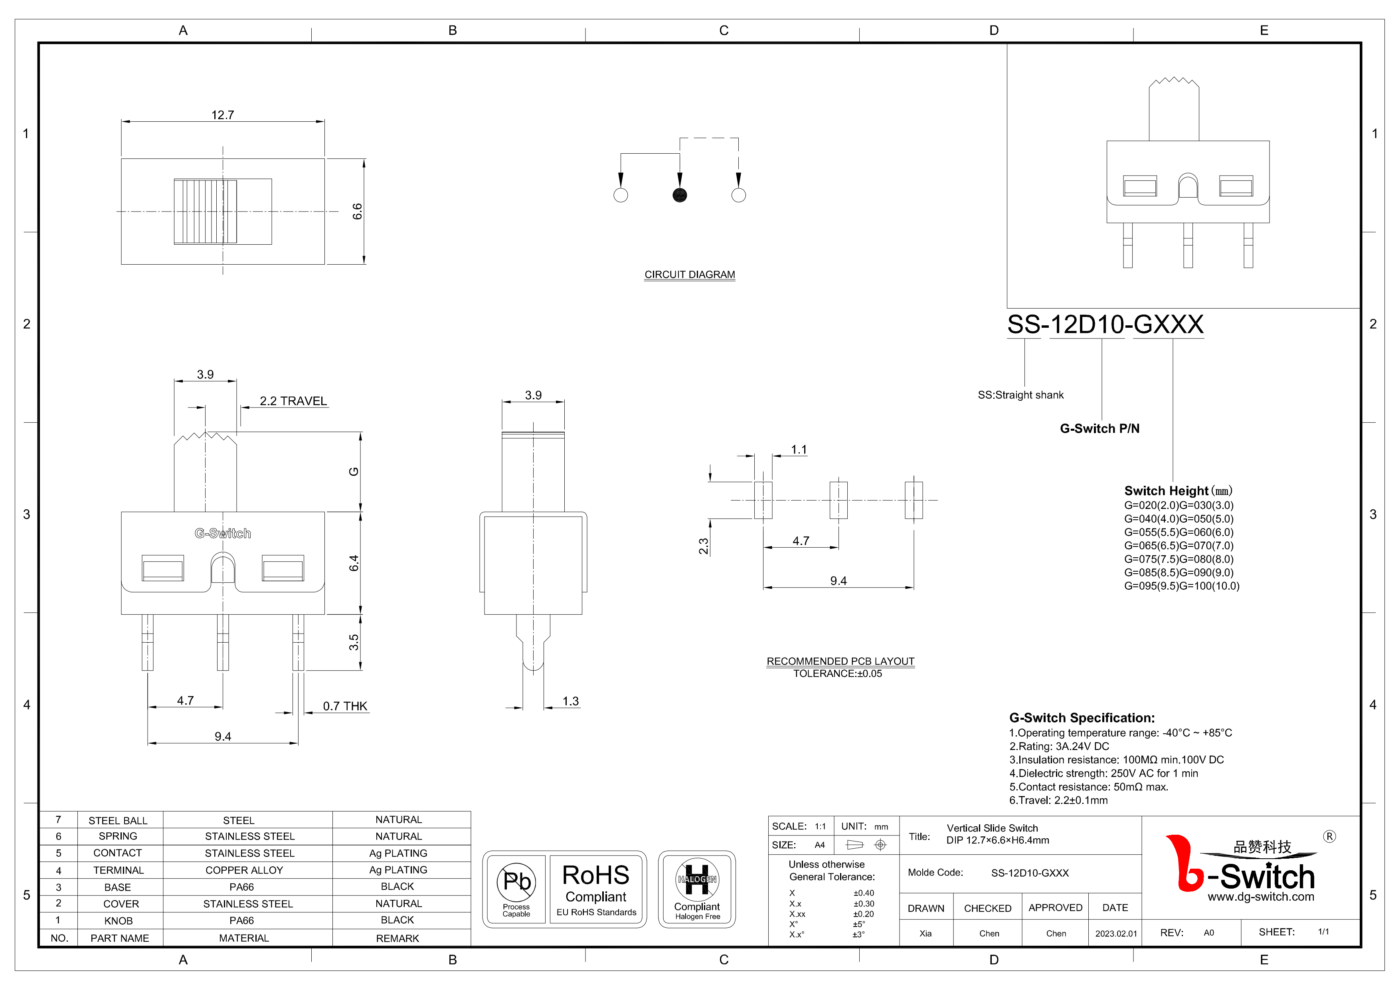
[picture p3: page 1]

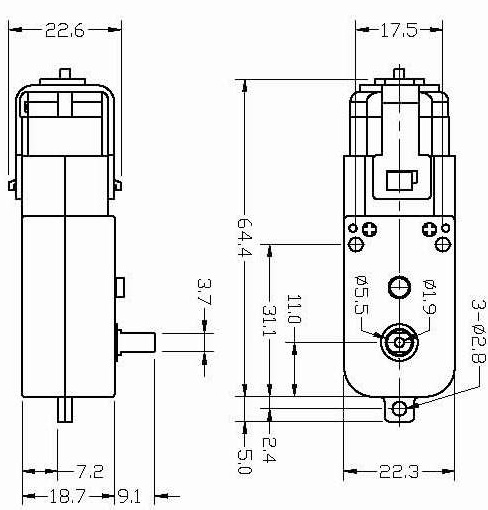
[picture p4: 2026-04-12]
Schemes/Yellow DC 3V–6V Gear Motor TT_specification2.webp

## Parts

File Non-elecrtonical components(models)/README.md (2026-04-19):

# **Models documentation**
This folder contains the complete 3D CAD models and manufacturing files for the team CyberBots WRO 2026 Future Engineers robot. All mechanical components were carefully designed and assembled to achieve our goal of completing the track in the shortest possible time while keeping the robot’s external structure as similar as possible to a real vehicle. The initial structural concept was inspired by the Mars Rover, particularly in terms of base layout, after which the design was further adapted to resemble a conventional ground vehicle. The design process focused on improving stability, component placement efficiency, and realistic vehicle proportions while ensuring reliable integration of all systems inside a chassis.





## **🎯Design Goals:**
Our design focused on achieving high performance while maintaining a structure similar to a real vehicle. Instead of minimizing size and weight, we optimized the chassis to complete the track in the shortest possible time while ensuring stability and reliable component placement. Special attention was given to realistic vehicle proportions and efficient internal layout so that all mechanical and electronic components could operate without interference inside a compact structure.

## **⚙️Steering and 4-Gear Mechanical Differential systems:** 
The steering system is designed as a hybrid LEGO and 3D-printed mechanism with the following goals:

 - Provide **precise and repeatable turning control** for accurate navigation on the WRO field
 
 - Use a **simple front-wheel steering mechanism** driven by a single servo motor for reliability and simplicity
 
 - Integrate a **LEGO differential system** to ensure smooth and stable wheel rotation during turns
 
 - Minimize **mechanical friction** by carefully aligning all moving components
 
 - Apply light lubrication to improve **movement consistency and efficiency**
 
 - Combine LEGO and 3D-printed parts to achieve a **balance between structural rigidity and custom precision parts**
 
 - Ensure stable and predictable behavior of the robot during movement on a **3×3 meter competition field**

Differential

https://github.com/user-attachments/assets/e802eda8-740b-4b7b-a47c-ce4926abeb2c

Снимок экрана 2026-04-19 041454

## **🏗️Chassis and Structural Design:**
- Provide a **strong and stable base structure** capable of supporting all electronic and mechanical components

 - Maintain an effective **balance between structural strength and lightweight construction** to improve speed and efficiency
 
 - Use an **initial layout inspired by the Mars Rover platform** to improve stability and component distribution
 
 - Adapt the final structure to resemble a **conventional ground vehicle design** with realistic proportions
 
 - Avoid adding a suspension system because the **competition track is flat and predictable**
 
 - Reduce **unnecessary weight and mechanical complexity** by using a rigid chassis instead of shock absorbers
 
 - Integrate **LEGO structural elements together with custom 3D-printed parts** for precise mounting and compact component placement
 
 - Ensure stable positioning of key systems such as the **differential, steering system, motors, and control electronics**

Снимок экрана 2026-04-19 041640

 ## **🏭Manufacturing Process:**
 We utilized a locally available 3D printer within our workspace to manufacture custom-designed components. This allowed us to rapidly prototype parts, test different design iterations, and refine mechanical performance efficiently during the development process.

### **🖨️CAD & Slicing Software Integration:**
 - **Design Platform:** Autodesk Fusion for comprehensive 3D modeling, simulation, and engineering analysis
 
 - **Slicing Software:** Creality Print 7 for optimized print preparation and manufacturing parameter management
 
 - **3D Printer:** Creality Ender 3 V3 SE FDM printer used for in-house fabrication of custom mechanical components
 
 - **Workflow Integration:** Seamless transition from CAD design to manufacturing-ready files for rapid prototyping and production

 

## **🛠️Infilling Selection Process:**
**Final Infilling:** Gyroid infill

**Infilling Choices && Explanations:**
- **Gyroid infill** — Selected as the final choice due to its optimal balance between weight reduction and mechanical strength, providing high structural rigidity with minimal material usage
 
- **Honeycomb infill** — Offered good strength but resulted in higher material consumption and weight
 
- **Linear infill** — Lightweight but insufficient in strength for load-bearing components
 
- **Cubic infill** — Provided uniform strength but was less efficient in weight optimization compared to gyroid

## **🔥Engineering Challenge:**
During the mechanical design process, we encountered several structural challenges that required iterative improvements:

- **Front bumper and wheel rotator sharing the same space:**
The initial design resulted in a spatial conflict where the front bumper and the wheel rotator (steering mechanism) occupied overlapping space. This caused limitations in assembly and restricted the movement of the steering system. To solve this issue, we redesigned the bumper in Autodesk Fusion, adjusting its geometry and repositioning it to provide dedicated clearance for the wheel rotator, ensuring full steering functionality without compromising the overall structure.
#### **First Model**
Снимок экрана 2026-04-16 015208

#### **Improved Model**
Снимок экрана 2026-04-16 015010

- **Upper enclosure cover interfering with Raspberry Pi connections:**
The top cover of the electronics enclosure, which holds the Raspberry Pi, partially blocked access to several GPIO pin connections. This problem was solved by physically removing a small section of the cover that did not affect the structural integrity or external appearance of the robot, allowing proper cable routing and reliable connections.
#### **First Model**
Снимок экрана 2026-04-16 015659

#### **Modified Model**
 

- **Differential manufacturing limitations due to 3D printing constraints:**
The original plan was to manufacture a custom differential using 3D printing. However, due to printer limitations and insufficient precision for small mechanical tolerances, the printed design could not function reliably. As a result, we switched to a LEGO-based differential system and integrated its components into our drivetrain. This solution ensured smooth and reliable torque distribution while maintaining mechanical simplicity and reducing manufacturing risks.

- **Front fender interference**
During early mechanical testing, the front fenders were found to interfere with wheel rotation during steering due to the compact chassis layout. To improve steering clearance and ensure smooth turning performance, the fenders were removed from the final design. This modification significantly increased maneuverability and improved overall navigation stability during autonomous runs on the WRO field.

## **🧩Assembly Guide**
**Step-by-Step Assembly Process:**



#### **Phase 1: Base Structure & Foundation Assembly**

- **Bottom Layer Construction:** The assembly process began with the bottom structural layer, forming the main chassis “floor” as the primary load-bearing foundation for all components
 
- **Electronics Mounting:** Installation of the Raspberry Pi and supporting electronic components directly onto the base layer for compact and stable integration

- **Wiring & Connectivity Setup:** Organization and connection of all power and control wiring to ensure clean routing and accessibility

- **Motor Installation:** Integration of the Yellow DC TT Gear Motor (3V–6V, 130–290 rpm, 1:48 gear ratio) as the main drivetrain motor, mounted securely onto the base structure

- **Power System Integration:** Placement of the battery in an optimized position to maintain stable weight distribution and balance

- **Initial Mechanical Alignment:** Early verification of structural alignment to ensure correct positioning of drivetrain components before upper assembly

#### **Phase 2: Upper Structure & Mechanical Systems**

- **Chassis Completion:** Installation of upper structural elements to protect internal systems while maintaining modular accessibility

- **Steering System Integration:** Assembly of the front steering mechanism, including rotator system, with adjustments to avoid spatial conflicts with the bumper

- **Wheel & Differential Installation:** Final integration of wheels and LEGO differential system, ensuring smooth torque transfer and correct alignment with the drivetrain

#### **Phase 3: Final System Assembly & Validation**

- **Full System Integration:** Connection of mechanical, electrical, and control systems into a unified working robot

- **Structural Verification:** Final checks of mechanical stability, component fitment, and assembly integrity

- **Functional Testing:** Validation of drivetrain efficiency, steering response, and overall robot movement performance

## **🔄Component Development & Engineering Itegration**
**Component Development & Engineering Iteration**

- Gear system evolution: The drivetrain was developed through multiple iterations, combining LEGO gear components with optimized alignment to improve smooth torque transfer and reduce friction losses.

 - Steering mechanism refinement: The steering system was repeatedly redesigned to solve spatial conflicts with the bumper and wheel rotator, achieving precise control with minimal mechanical restriction and improved turning clearance.
 
 - Structural component optimization: The chassis and body components were iteratively adjusted to balance strength and lightweight construction, ensuring stable mounting of all electronics and mechanical parts under dynamic movement.
 
 - Differential integration approach: Due to limitations of the 3D printer in producing small and precise mechanical tolerances, a LEGO differential system was adopted and successfully integrated into the drivetrain for reliable and smooth operation.
 
 - System integration validation: Continuous testing ensured compatibility between LEGO mechanical elements, 3D-printed parts, and the Raspberry Pi-based control system, improving overall system reliability and assembly efficiency.

## **🎯Performance Analysis**

## **📊Engineering Calculations & Performance Validation**

## **📁Complete Manufacturing File Repository**
#### **3D Printing Files & Assembly Specifications**
| Component  | Quantity | Description | CAD Photo Preview |
|---|---|---|---|
| **Main Chassis** | 1 | Primary structure with integrated mounting system | Снимок экрана 2026-04-19 041640 |
| **LEGO 4-Gear Differential**  | 1 |A LEGO differential is a drivetrain component that distributes torque between the left and right wheels, allowing them to rotate at different speeds during turns for smooth and stable cornering. |  |
| **Bumper** | 1 |  A front bumper is a structural protective component mounted on the front of the robot, designed to absorb minor impacts and protect internal systems while maintaining clearance for the steering mechanism, and it also serves as a mounting point for LED headlights | Снимок экрана 2026-04-16 015010 |
| **Back right wheel fender** |  1 |  Protective wheel panel providing structural protection and body support. | Снимок экрана 2026-04-16 142714  |
| **Back left wheel fender** | 1 | Protective wheel panel providing structural protection and body support. | Снимок экрана 2026-04-16 142714 |
| **Front left wheel fender** | 1 | Protective wheel panel providing structural protection and necessary clearance for steering rotation. | Снимок экрана 2026-04-16 142253 | 
| **Front right wheel fender** | 1 | Protective wheel panel providing structural protection and necessary clearance for steering rotation. | Снимок экрана 2026-04-16 142253  | 
| **Disk for wheel** | 4 | Custom wheel disk ensuring reliable connection between the wheel and drivetrain. | Снимок экрана 2026-04-16 120709  |
| **Servo Gear** | 1 |  Transmission gear transferring rotation from the servo motor to the steering mechanism. | Снимок экрана 2026-04-16 113454  | 
| **Left holder** | 1 | Structural holder designed to simplify safe robot handling and transportation. | Снимок экрана 2026-04-16 143249 |
| **Right holder** | 1 | Structural holder designed to simplify safe robot handling and transportation. | Снимок экрана 2026-04-16 143249  | 
| **Lidar holder** | 1 | Mount designed for stable LiDAR sensor installation. | Снимок экрана 2026-04-16 140928 | 
| **Lower left body panel** | 1 | Body panel used to reinforce chassis structure. |  Снимок экрана 2026-04-16 140342 | 
| **Lower right body panel** |  1 | Body panel used to reinforce chassis structure. | Снимок экрана 2026-04-16 145644  | 
| **Upper right body panel** |  1 | Body panel used to protect internal robot components. | Снимок экрана 2026-04-16 135838 |  
| **Upper left body panel** |  1 | Body panel used to protect internal robot components. | Снимок экрана 2026-04-16 140112  |  
| **Motor holder** |  1 | Mount designed for secure drivetrain motor fixation. | Снимок экрана 2026-04-16 113226 | 
| **Raspberry upper holder** |  1 | Mount used to secure the Raspberry Pi board. | Снимок экрана 2026-04-16 015659  | 
| **Raspberry lower holder** |  1 |  Mount used to secure the Raspberry Pi board. | Снимок экрана 2026-04-16 113956 |
| **Swich 2 Axis** |  1 | Mount designed for installation of the 2-axis control switch. | Снимок экрана 2026-04-16 141304 | 
| **Wheel 45 degree Rotator** |  1 | Steering mechanism component enabling wheel rotation up to 45°. |  Снимок экрана 2026-04-16 120034 |  
| **180 degree gea** |  1 | Gear used for rotation of front wheels within the steering mechanism. | Снимок экрана 2026-04-16 113746 |
| **Wheel holder left** | 1 | Mount designed to secure the wheel and maintain correct alignment. | Снимок экрана 2026-04-16 135411 | 
| **Lego wheels** | 4 |  Standard LEGO wheel used for robot movement, providing traction, stability, and reliable motion on the competition field. | Снимок экрана 2026-04-16 165149 |  

## **🚀Engineering Design & Development Process**
#### **🔄Comprehensive Iterative Engineering Approach**

**Conceptual Design & Requirements Analysis**
 - Competition size constraint analysis and chassis dimension optimization
 
 - Steering system layout planning with rotation clearance consideration for front wheel movement
 
 - Strategic placement planning of Raspberry Pi, LiDAR sensor, drivetrain motor, and battery for balanced weight distribution
 
 - Structural holder integration for safe robot handling and transportation

**Precision CAD Modeling & Engineering Simulation**

-  Detailed CAD modeling of custom mechanical components in Autodesk Fusion
 
-  Steering mechanism geometry validation including servo gear and 45° wheel rotator alignment
 
-  Spatial verification to prevent interference between steering system and front bumper
 
-  Integration modeling of LEGO differential with drivetrain structure

**Prototyping & Performance Optimization**
 - Multiple iterations of 3D printed components for improved fit and mechanical stability
 
 - Testing of different infill structures (gyroid, honeycomb, linear, cubic) for strength-to-weight optimization
 
 - Selection of gyroid infill pattern to achieve optimal balance between durability and lightweight structure
 
 - Verification of LiDAR holder positioning for stable sensing performance

**Production Engineering & System Validation**
 - Optimization of printing parameters for reliable and repeatable part production
 
 - Development of structured assembly sequence starting from electronics base integration followed by drivetrain installation
 
 - Full mechanical system alignment verification including wheels, steering system, and differential
 
 - Competition-condition movement testing including drivetrain efficiency and steering responsiveness
 
 - Final validation of structural stability, LED headlight mounting

## ✅Engineering Validation & Testing Protocols

### 🧪Mechanical System Verification & CAD Design Testing

- Differential Operation Validation: Testing of LEGO 4-gear differential confirmed stable torque distribution and smooth drivetrain performance during autonomous movement.
- Steering System Verification: Front steering linkage tested in real driving conditions to ensure reliable wheel rotation clearance and stable turning behavior on the WRO field.
- Structural Integrity Assessment: PETG chassis components validated through repeated movement tests over minor surface irregularities to confirm strength and durability.
- Component Placement Optimization: CAD-based layout adjustments performed to improve internal spacing, accessibility, and weight distribution stability.

**Fender Design Modification:** Front fenders removed after testing revealed interference with wheel rotation during turning, improving steering freedom and overall navigation performance.

### 🏆Competition Readiness & Reliability Engineering

- Regulation Compliance Verification: Full compliance with WRO Future Engineers 2026 regulations including maximum robot dimensions of 300 × 200 × 300 mm and fully autonomous onboard operation using integrated sensors and computing systems.
- Operational Reliability Demonstration: Repeated autonomous driving tests performed on the 3 × 3 meter competition field confirming stable navigation, obstacle detection, and consistent steering performance.
- Maintenance & Service Protocols: Modular chassis structure and accessible Raspberry Pi ports allow fast software updates, wiring inspection, and mechanical adjustments during testing and competition preparation.
- Backup System Preparation: Spare mechanical components, electronic modules, and pre-tested software configurations prepared to ensure quick recovery in case of unexpected issues during competition runs.

------------------------------------------------------------------------------------------------------------------------------------------------------------------
This comprehensive mechanical documentation provides full transparency into our design process, CAD development, manufacturing methods, validation procedures, and engineering decisions. Every part of our mechanical system has been optimized for the requirements of the WRO Future Engineers 2026 category, focusing on compact design, stability, and reliable autonomous performance on the 3 × 3 meter competition field.

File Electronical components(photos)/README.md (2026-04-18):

# **Electronics**
This folder contains supplementary materials for Team CyberBots’s WRO 2026 Future Engineers robot, including component images, technical documentation and faced problems during development.

## **Movement & Power Components**
| Components | Image | Description |
|---|---|---|
| Battery 7.4V |  Battary 7 4 v | Lithium polymer battery pack / custom 2S LiPo battery – 7.4V, 3000mAh, Charge 0.5C, Discharge 1C, Size 13×42.5×98 mm, Weight ~108 g. |
| yellow toymotor dims |  yellow_toymotor_dims |Yellow DC 3V–6V Gear Motor TT for Intelligent Car / Robot Wheels – Voltage 3–6V, No-load current 160–240 mA, No-load speed 130–290 rpm, Gear ratio 1:48, Single axis. |
| mg996r v17 | mg996r v17 | MG996R V17 Servo Motor – High torque, Digital, Rotation ~180°, Operating voltage 4.8–7.2 V, Speed 0.17 s/60° (6 V), Metal gears, Standard size. |
| HW-411 | HW-411 | HW‑411 DC‑DC Buck Converter Module – Adjustable step‑down voltage regulator (LM2596S), Input 4–40 V, Output 1.25–35 V (adjustable), Max current ≈3 A, High efficiency (~92%), Overheat and short‑circuit protectio |

## **Electronic Components**
| Components | Image | Description |
|---|---|---|
| USB 8MP 4K 60fps Camera | Cam V2 1 v1 | USB 8MP 4K 60fps Camera with IMX415 Sensor and Microphone, Day & Night Wide-Angle Surveillance HD CCTV System |
| DRV8833 | DRV8833  | DRV8833 Dual DC Motor Driver Module – Dual H-bridge motor driver, operating voltage 2.7–10.8 V, controls 2 DC motors, output current 1.5 A per channel, supports PWM control, built-in protection circuits. |
| PCA9685 v18 | PCA9685 v18  | PCA9685 16-Channel PWM Servo Driver Module (I2C) – Controls up to 16 servos, 12-bit PWM resolution (4096 steps), communication via I2C (SDA/SCL), logic voltage 3.3 V / 5 V compatible, adjustable PWM frequency ≈24–1526 Hz, supports chaining up to 62 modules. |
| RASPBERRY_PI5_1 | RASPBERRY_PI5_1  | Raspberry Pi 5 (1GB) – Quad-core 2.4 GHz Cortex-A76 CPU, 1 GB LPDDR4X RAM, VideoCore VII GPU, Wi-Fi (802.11ac) + Bluetooth 5.0, Gigabit Ethernet, 2× USB 3.0 + 2× USB 2.0, dual 4K HDMI output, PCIe 2.0, 40-pin GPIO, power 5 V / 5 A via USB-C. |
| RPLIDAR | RPLIDAR  | Xiaomi LiDAR Sensor (e.g., TOF / 360°)* – Long‑range distance measurement up to ~10–12 m, 360° scanning, high‑precision time‑of‑flight (ToF) / laser ranging, fast sampling, low‑power, interface UART / I2C / SPI (зависит от модели), used for SLAM and robot navigation. |
| SS12D10_90_Degree | SS12D10_90_Degree | SS12D10 90° Slide Switch (DIP) – SPDT slide switch, 90° actuation, DIP package, rated current ≈0.3–1 A, voltage ≈12–24 V DC, used for power/control switching in circuits. |

## **Challenges and Problems Faced During Development**

**Component specifications (especially LiDAR)**

Another challenge was finding reliable technical specifications for some components, especially the LiDAR sensor. It was difficult to find complete official datasheets in PDF format, which created uncertainty during integration and system planning. Because of this, we collected and compared specifications from different sellers and technical sources and used them as reference values.

**Limited internal space and Raspberry Pi placement**

Initially, the Raspberry Pi was installed at the rear part of the robot, but this placement interfered with the LiDAR operation and reduced its effective sensing performance. Moving the Raspberry Pi to a lower position required reorganizing multiple components inside a very limited internal space. It was difficult to fit all electronics correctly, but after several hours of adjustments, we successfully arranged all components inside the chassis.

**Electronic architecture and GPIO planning**

Designing the electronic architecture and wiring layout was also challenging. Several modules had to be connected to the Raspberry Pi, and the limited number of available GPIO pins required careful planning. We studied the pin configuration in detail to ensure correct communication between all components and stable system operation.

## **Notes**
- All component specifications are sourced from official manufacturer datasheets.
- Development photos showcase our hands-on manufacturing and testing processes.

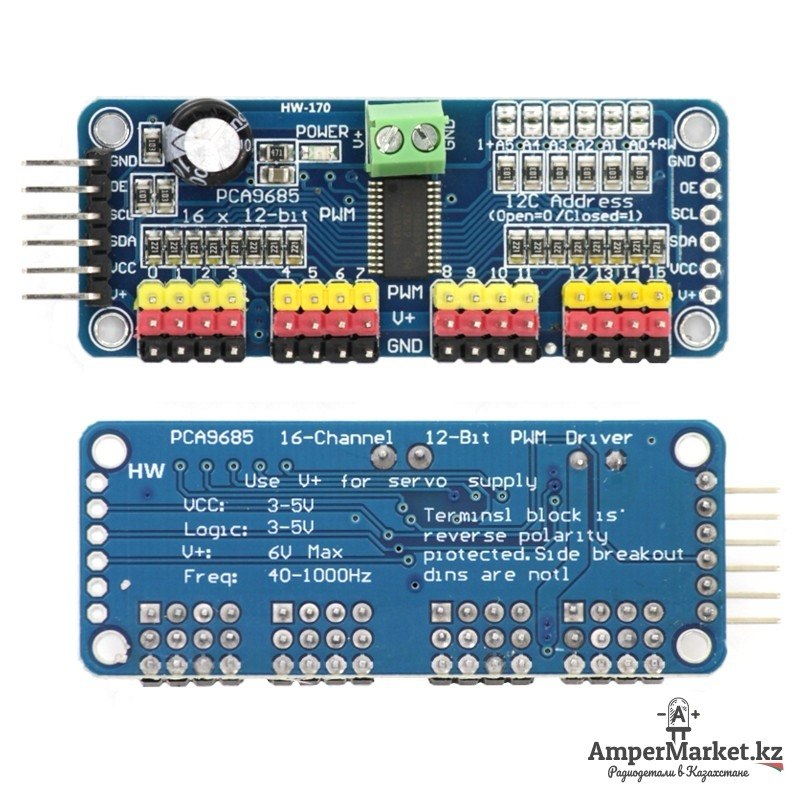
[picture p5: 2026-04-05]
Electronical components(photos)/PCA9685 v18.jpg

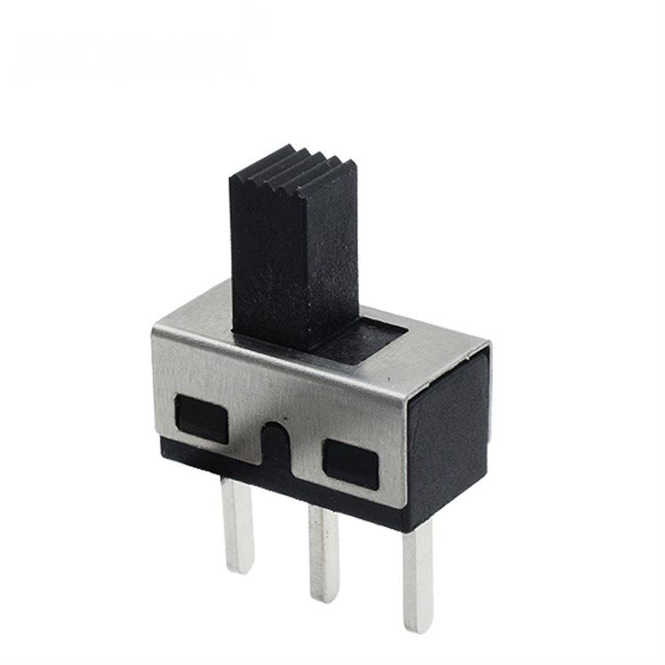
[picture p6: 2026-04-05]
Electronical components(photos)/SS12D10_90_Degree.jpg

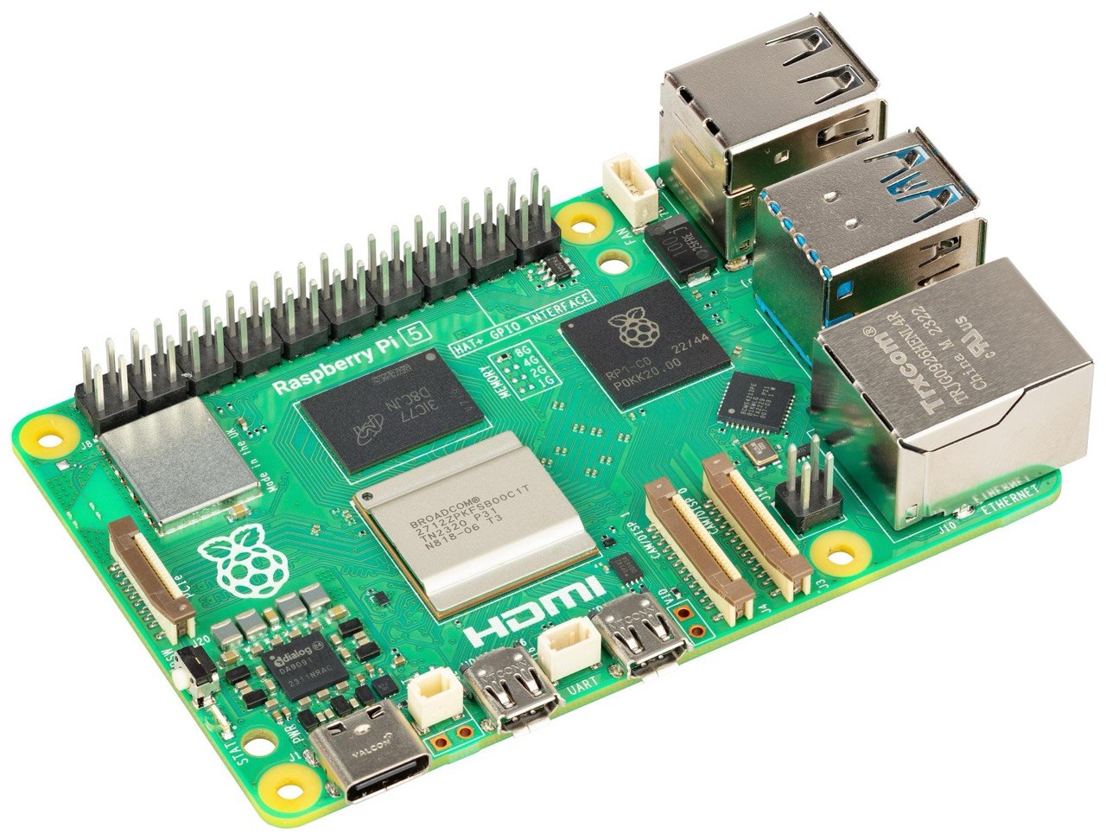
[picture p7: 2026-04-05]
Electronical components(photos)/RASPBERRY_PI5_1.jpg

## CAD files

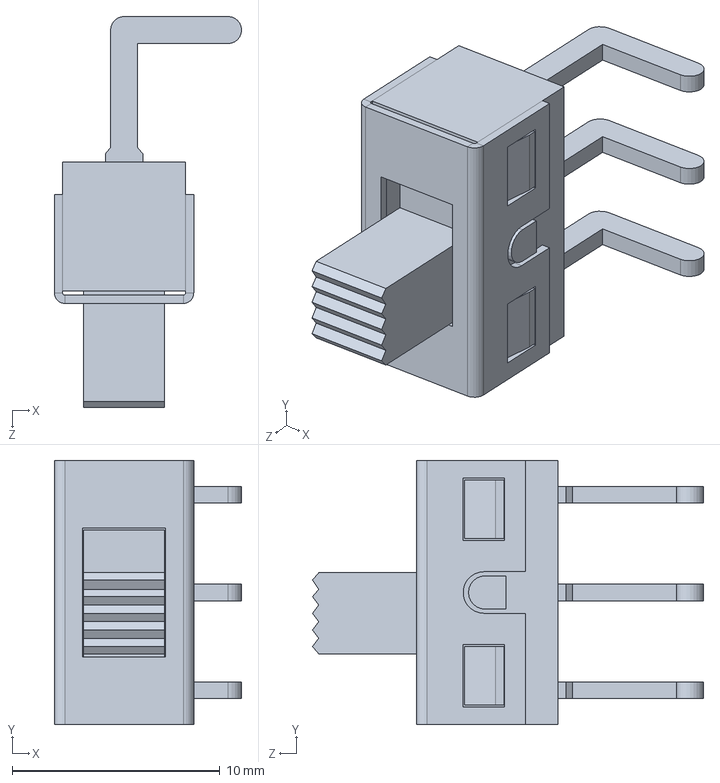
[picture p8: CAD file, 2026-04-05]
Electronical components (CAD)/SS12D10_90_Degree.SLDPRT
9.00 x 12.7 x 18.8 mm

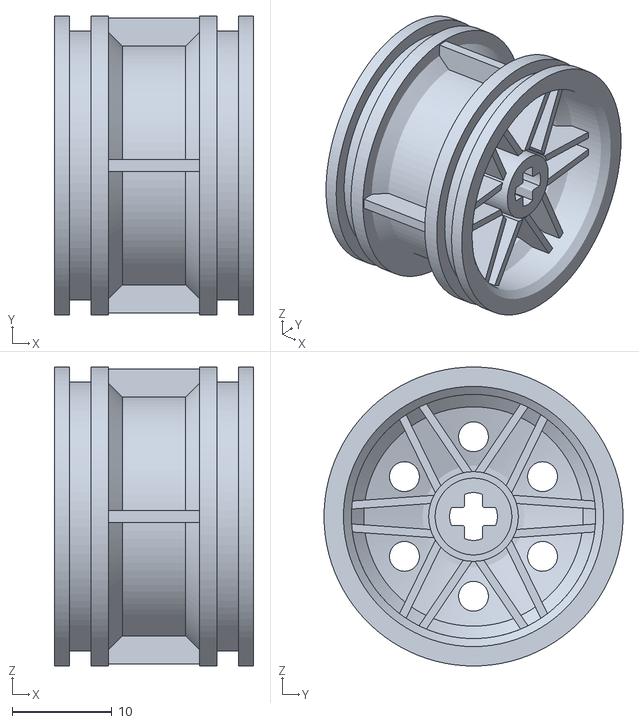
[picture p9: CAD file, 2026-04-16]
Non-elecrtonical components(models)/Lego.stl
20.0 x 30.0 x 30.0

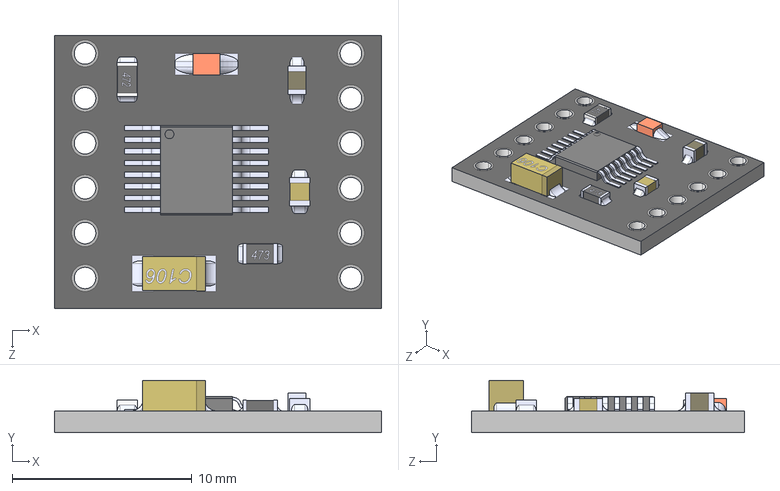
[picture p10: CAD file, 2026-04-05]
Electronical components (CAD)/DRV8833.STEP
18.2 x 2.91 x 15.2 mm

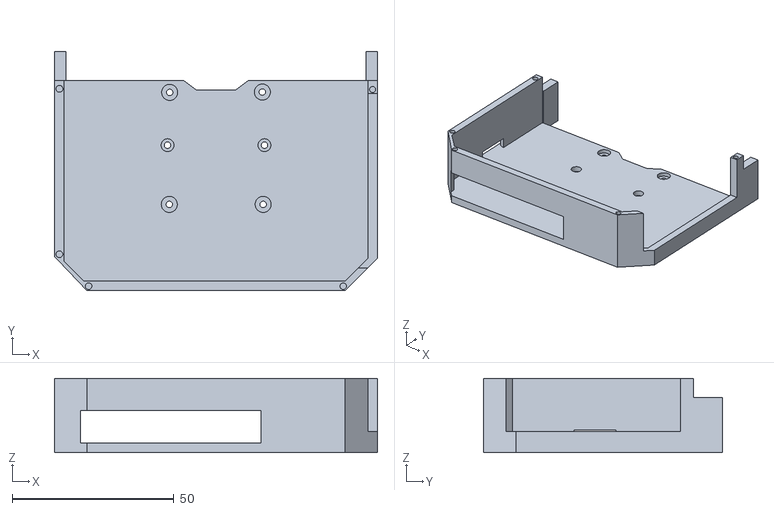
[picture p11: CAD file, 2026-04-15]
Non-elecrtonical components(models)/Raspberry_PI_5_holder_Prime.stl
100.0 x 74.0 x 23.0

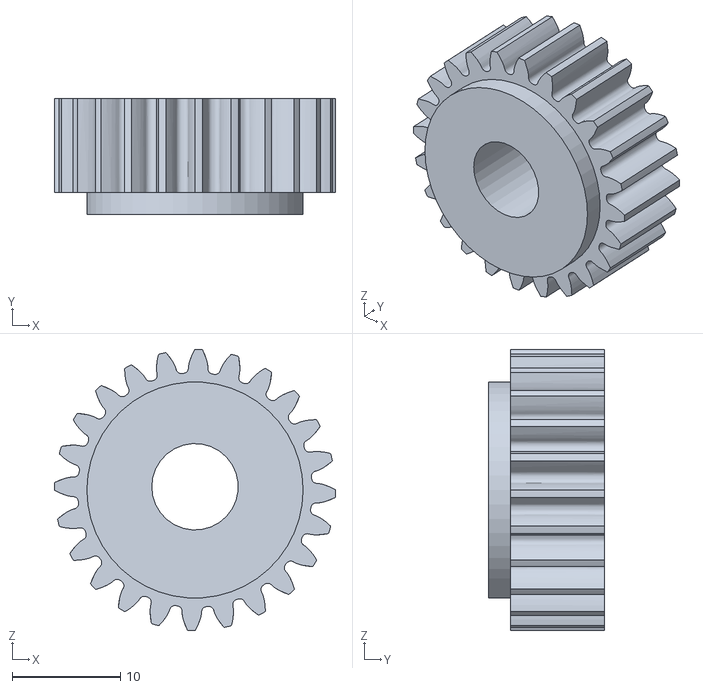
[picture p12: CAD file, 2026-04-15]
Non-elecrtonical components(models)/Gear_Servo.stl
26.0 x 10.7 x 26.0

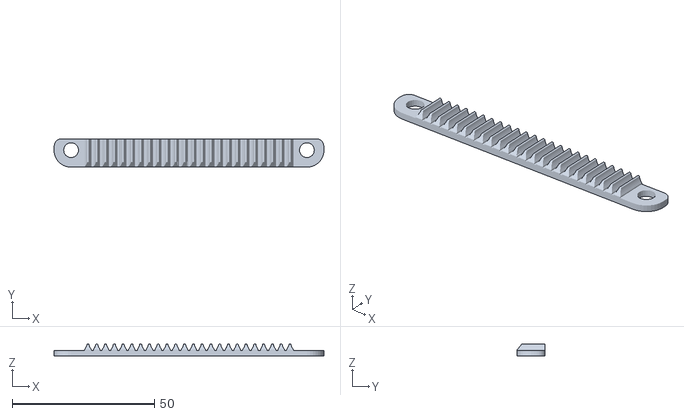
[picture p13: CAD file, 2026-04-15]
Non-elecrtonical components(models)/180Degree_Gear.stl
94.9 x 10.0 x 4.35

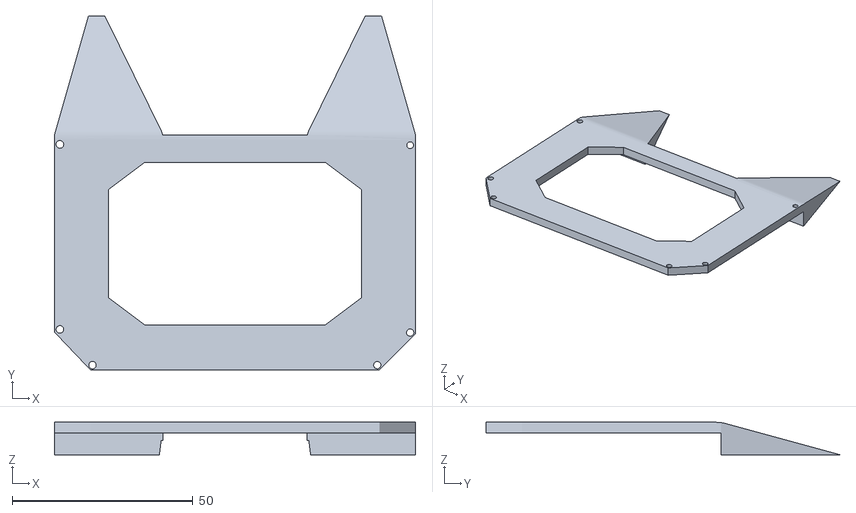
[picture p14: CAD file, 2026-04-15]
Non-elecrtonical components(models)/Raspberry_PI_5_holder_Upper.stl
100.0 x 98.0 x 9.00

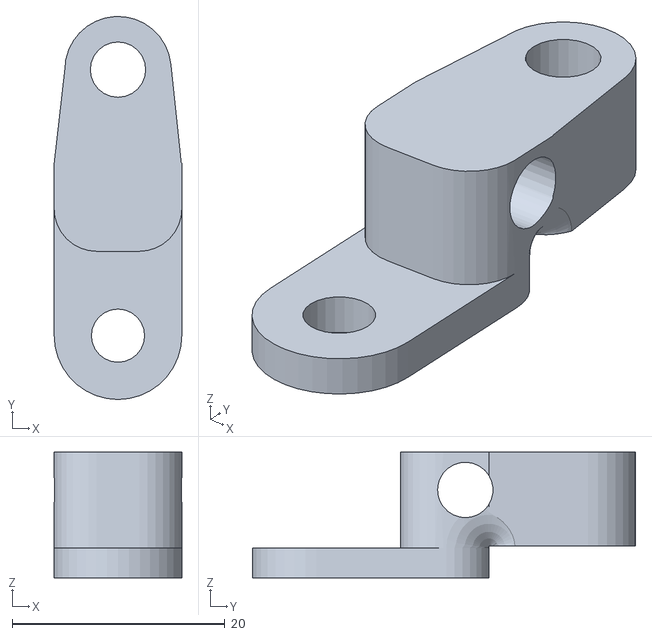
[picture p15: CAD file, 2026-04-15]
Non-elecrtonical components(models)/Wheel_45Degree_Rotator.stl
12.0 x 36.0 x 11.8

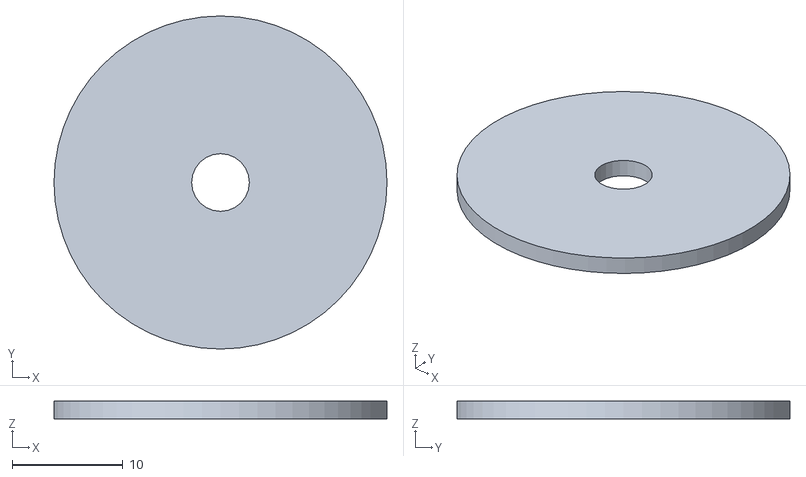
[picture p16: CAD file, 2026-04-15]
Non-elecrtonical components(models)/Disk_for_wheel.stl
30.0 x 30.0 x 1.60

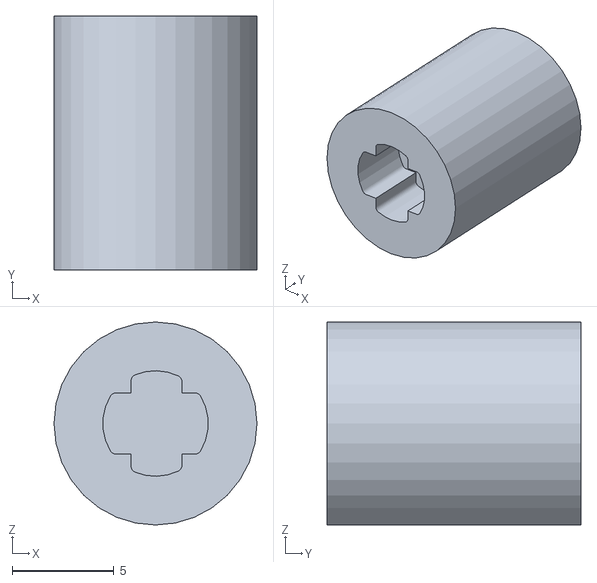
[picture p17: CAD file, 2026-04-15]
Non-elecrtonical components(models)/Swich_2Axis.stl
10.0 x 12.5 x 10.0

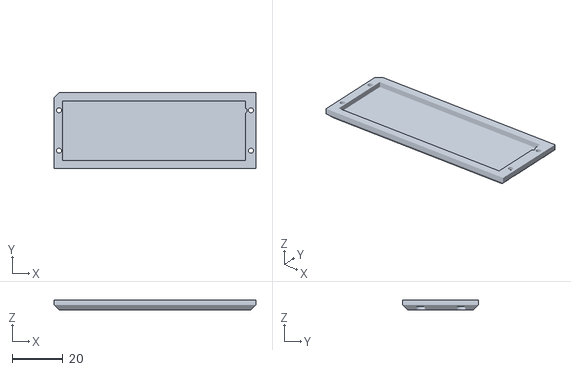
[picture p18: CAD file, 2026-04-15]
Non-elecrtonical components(models)/Motor_holder.stl
80.0 x 30.0 x 4.00

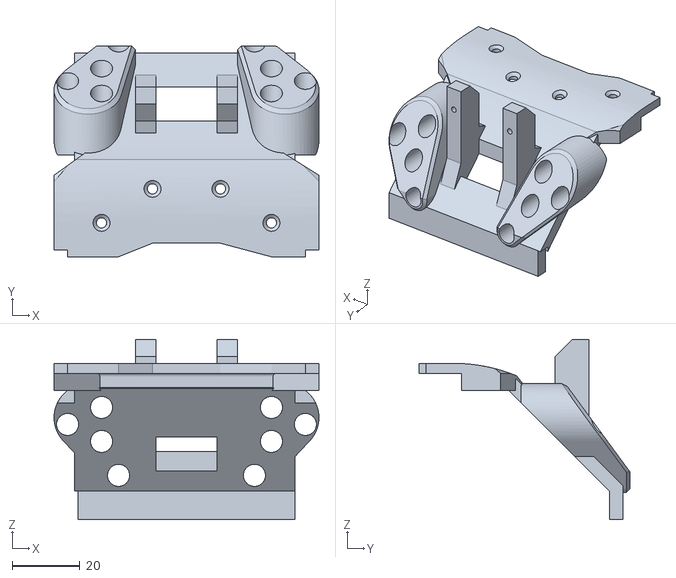
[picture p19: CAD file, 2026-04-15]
Non-elecrtonical components(models)/Bumper_V.2.stl
78.0 x 62.0 x 53.0

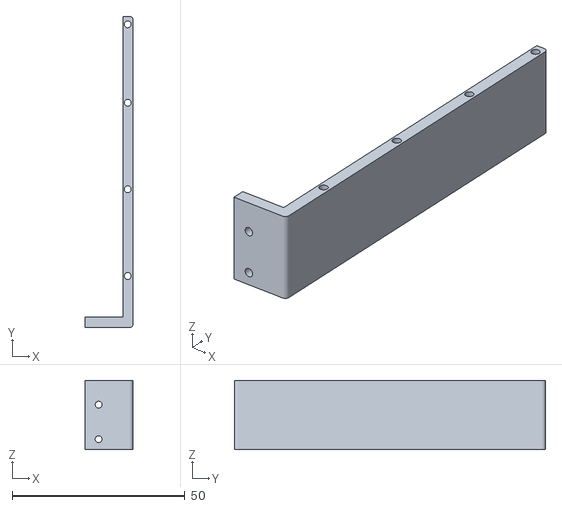
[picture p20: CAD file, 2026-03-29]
Non-elecrtonical components(models)/Rightside.stl
14.0 x 90.0 x 20.0

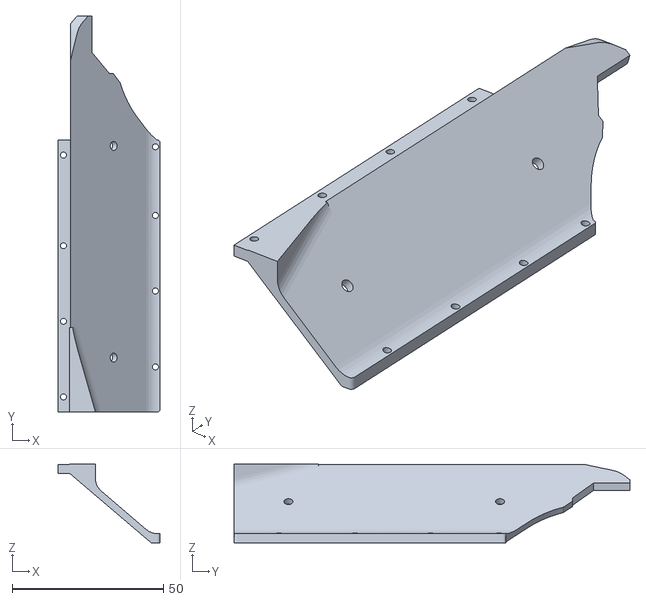
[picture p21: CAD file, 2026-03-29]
Non-elecrtonical components(models)/Upper_rightside.stl
33.9 x 131.0 x 26.0

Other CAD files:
Non-elecrtonical components(models)/LIdar_Holder.stl
Non-elecrtonical components(models)/Leftside.stl
Non-elecrtonical components(models)/WHeel_holderbodyright.stl
Non-elecrtonical components(models)/Wheel_holderleft.stl
Electronical components (CAD)/Battary 7.4 v.f3d
Electronical components (CAD)/Cam V2.1 v1.f3d
Electronical components (CAD)/PCA9685 v18.f3d
Electronical components (CAD)/mg996r v17.f3d
Electronical components (CAD)/yellow_toy_motor_dims.f3d
Non-elecrtonical components(models)/Back_Wheelleft.stl
Non-elecrtonical components(models)/Back_Wheelright.stl
Non-elecrtonical components(models)/Forward_Wheelleft.stl
Non-elecrtonical components(models)/Forward_wheelright.stl
Non-elecrtonical components(models)/Holder_left.stl
Non-elecrtonical components(models)/Holder_right.stl
Non-elecrtonical components(models)/Upper_leftside.stl

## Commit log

2026-04-05 Create ARDUINO
2026-04-12 Create Yellow DC 3V–6V Gear Motor TT_specification
2026-04-19 Add CAD photo previews to manufacturing components
    Added CAD photo previews for Main Chassis and LEGO 4-Gear Differential.
